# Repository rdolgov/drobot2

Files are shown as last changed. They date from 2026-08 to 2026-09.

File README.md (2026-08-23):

# drobot2

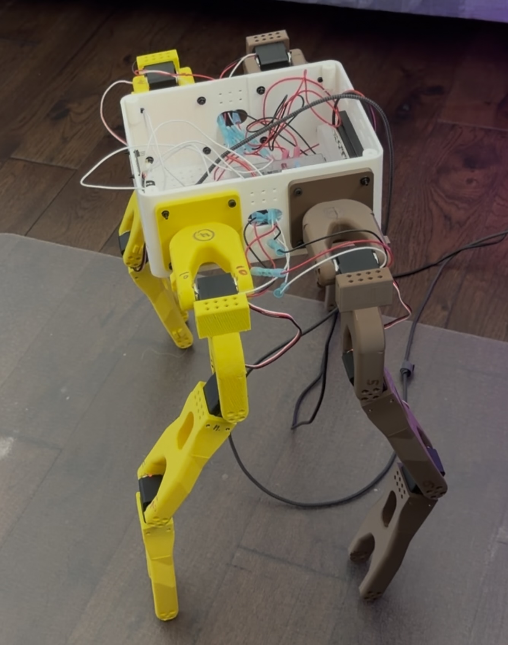
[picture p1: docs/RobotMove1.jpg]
Drobot2 robot in motion


Monorepo for the Drobot2 robot. Engineering areas are separated at the
repository root so CAD, simulation, hardware control, and electrical design
can evolve without sharing one package boundary.

## Physical robot reference

- Measured total assembled robot mass: approximately **3.18 kg** (converted
  from a 7 lb measurement), including the installed rear battery and its
  enclosure as configured on 2026-08-23.

Treat this as the current whole-robot measurement. Component-level CAD and
simulation mass ledgers may differ and should be reconciled against it when
preparing the next dynamics-model or RL-training revision.

## Project areas

- [`cad/`](cad/README.md) — parametric mechanical design,
  CAD-derived URDF generation, manufacturing exports, vendor geometry, and CAD
  review tooling.
- [`simulation/`](simulation/README.md) — Isaac Sim integration, reinforcement
  learning, trained policies, simulator exports, evaluation media, and
  simulation documentation.
- [`hardware/`](hardware/README.md) — one-leg commissioning and four-leg
  hardware control/test applications.
- [`onboard/`](onboard/README.md) — ROS 2 Raspberry Pi runtime, LAN browser
  control, ROS services/topics, and boot-service setup.
- [`electrical/`](electrical/README.md) — power distribution, fusing, wiring,
  schematics, BOM, and power-budget planning.

Run domain-specific commands from the repository root unless that area's
README says otherwise. Shared architecture and repository conventions are
indexed under [`docs/`](docs/README.md). Generated caches and local
environments remain ignored.

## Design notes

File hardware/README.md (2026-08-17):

# Drobot hardware control

This area owns physical robot configuration, commissioning, and guarded local
control software.

## Layout

- [`robot-runtime/`](robot-runtime/README.md) — shared real-robot manifest,
  calibrated servo profiles, neutral centers, and operational helper scripts.
- [`test-apps/`](test-apps/README.md) — one-leg and four-leg commissioning
  applications. These consume `robot-runtime/`; they do not own robot state.

The Raspberry Pi package under [`../onboard/`](../onboard/README.md) reuses
these transport, dashboard, gait, profile, and calibration sources through a
ROS 2 node; it does not maintain a second hardware configuration.

Mechanical design lives in `cad/`, simulation validation in `simulation/`,
and power-system planning in `electrical/`.

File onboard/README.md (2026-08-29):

# Raspberry Pi ROS 2 onboard controller

The selected learned walking policy has a standalone, print-only runtime under
[`policy-runtime/`](policy-runtime/README.md) and a guarded real-motor rollout
inside the port 8080 dashboard. The real rollout uses the BNO085 plus live
12-joint feedback, runs for at most five seconds, and keeps the manual dashboard
as the only servo-bus owner. Stop the port 8090 print-only service before using
the real RL control so only one process reads the BNO085.

See [`docs/pi5-dog-bringup.md`](docs/pi5-dog-bringup.md) for the checked Pi
state, exact setup commands, power notes, and the staged safety plan for moving
from printed targets to real motor control.

This area packages the existing Drobot motor session and browser dashboard as
a ROS 2 node for an onboard Raspberry Pi. The Pi owns the USB servo bus, serves
the control page to computers on the same network, publishes telemetry, and
accepts the same walking commands through ROS services or a ROS command topic.

The package does not copy calibration or gait equations. It imports:

- `hardware/test-apps/one-leg-testbed` for the Feetech transport and calibrated
  angle conversion;
- `hardware/test-apps/four-leg-dashboard` for the twelve-servo session, browser
  UI, continuous distributed crawl, and continuous diagonal-pair gait; and
- `hardware/robot-runtime/four-leg.toml` plus its four tracked servo profiles
  and calibration JSON files as the physical robot source of truth.

## Standalone manual/IK dashboard

The previous inverse-kinematics and manual-walk page can run on the Pi before
ROS 2 is installed. Install it once:

```bash
bash onboard/scripts/install-manual-runtime.sh
bash onboard/scripts/install-manual-web-service.sh --start
```

Open `http://pi5-dog.local:8080/` from a phone or computer on the same trusted
network. The tracked service starts in **DEMO / NO MOTOR OUTPUT** mode. It uses
the real robot profiles, inverse kinematics, crawl logic, and UI with twelve
simulated motors, but it does not open a USB serial device.

After the Feetech USB adapter is connected to the Pi, the power warning is
resolved, and the complete robot is safely supported, edit
`/etc/default/drobot-manual-web`:

```text
DROBOT_MANUAL_DEMO=false
DROBOT_MANUAL_SERIAL_PORT=/dev/ttyUSB0
```

Then restart it with `sudo systemctl restart drobot-manual-web`. Hardware mode
opens the bus, requires all 12 configured IDs, and disarms them before serving
the page. Never run this standalone service and the future ROS motor-owner node
at the same time.

Keep `DROBOT_MANUAL_FALLBACK_DEMO=false` for a robot configured in hardware
mode. Port 8080 remains available as a hardware diagnostics page if the USB
adapter or any configured motor is missing, but every motion control stays
disabled until automatic recovery verifies all 12 IDs and disarms them. Set the
fallback to `true` only when an intentional simulated dashboard is preferred.
The page's mode badge always shows whether output is simulated or connected to
hardware.

### Update an existing Pi dashboard

From the existing clone on the Pi, update the checked-out branch and refresh
the editable runtime installation:

```bash
cd ~/drobot2
git pull --ff-only
bash onboard/scripts/install-manual-runtime.sh
sudo systemctl restart drobot-manual-web
sudo systemctl status drobot-manual-web --no-pager
```

Reload port 8080 after the restart. Confirm the mode badge, `12 / 12` online,
`0 / 12` armed, plausible voltage and temperature, and no fault before using a
whole-robot control. **TEST DISTRIBUTED CRAWL** and **TEST DIAGONAL PAIRS** then
continue until **STOP + STABLE HOLD**. The stop returns to the four-foot gait
stance and keeps torque armed; use **DISARM ALL 12** when support can safely be
removed. A minor off-stance start is accepted and ramped into the computed gait
stance; it is not permission to start from a
folded, collided, unsupported, or visibly damaged pose.

After **SET GAIT START STANCE** reports `COMPLETE / HOLDING`, **TEST DISTRIBUTED
CRAWL** can start directly while all 12 motors continue holding that verified
stance. Partial or unrelated armed configurations remain blocked.

The power panel also shows a basic 3S charge indicator from the last disarmed
idle-voltage reference. It is a pack-level estimate, not a substitute for
checking all three cells through the balance connector.

## Supported Pi baseline

The current `pi5-dog` baseline is a Raspberry Pi 5 with **Ubuntu Server 26.04
64-bit (arm64)** and **ROS 2 Lyrical**. Lyrical supports Ubuntu 26.04 on arm64,
and the image's Python version satisfies the repository's Python
3.11-or-newer requirement.

Official references:

- [ROS 2 Lyrical installation](https://docs.ros.org/en/lyrical/Installation.html)
- [ROS 2 Lyrical Ubuntu arm64 binary support](https://docs.ros.org/en/lyrical/Installation/Alternatives/Ubuntu-Install-Binary.html)
- [Ubuntu Server setup on Raspberry Pi](https://ubuntu.com/tutorials/how-to-install-ubuntu-on-your-raspberry-pi)

Raspberry Pi OS is not the tracked installation target. A source-built or
containerized ROS installation can be added later without changing the package
interfaces.

## Layout

```text
onboard/
|-- ros2_ws/src/drobot_onboard/   ROS 2 ament_python package
|-- scripts/run-manual-web.sh     standalone manual/IK dashboard
|-- scripts/install-pi.sh         dependency install and colcon build
|-- scripts/start-onboard.sh      foreground launcher
`-- systemd/                      optional boot-service template
```

## 1. Prepare the Raspberry Pi

Install ROS 2 Lyrical using the official instructions, including the ROS base
binary archive or equivalent package set. Then install the local build and
serial-account prerequisites:

```bash
sudo apt update
sudo apt install -y git python3-venv ros-dev-tools avahi-daemon
sudo usermod -aG dialout "$USER"
```

Log out and back in after adding `dialout`. This permission is required for
`/dev/ttyUSB*` and `/dev/ttyACM*` devices.

Clone the repository on the Pi:

```bash
git clone YOUR_GITHUB_REPOSITORY_URL ~/drobot2
cd ~/drobot2
```

## 2. Install from the clone

From the repository root:

```bash
bash onboard/scripts/install-pi.sh
```

The script:

1. checks that ROS 2 and Python 3.11+ are available;
2. creates `onboard/.venv` with access to the system ROS Python packages;
3. installs both existing hardware-control packages in editable mode; and
4. builds `drobot_onboard` into `onboard/ros2_ws/install` with symlink install.

The environment, build, install, and log directories stay local and are
ignored by Git.

## 3. Start without hardware first

Demo mode creates twelve in-memory motors and does not open a serial port:

```bash
bash onboard/scripts/start-onboard.sh --demo
```

From another computer on the same network, open:

```text
http://RASPBERRY_PI_HOSTNAME.local:8080/
```

If `.local` name resolution is unavailable, use the Pi's IP address, such as
`http://192.168.1.42:8080/`.

## 4. Start with the robot bus

Connect the Feetech USB adapter and identify its Linux device:

```bash
ls -l /dev/ttyUSB* /dev/ttyACM* 2>/dev/null
```

Then start the controller:

```bash
DROBOT_SERIAL_PORT=/dev/ttyUSB0 bash onboard/scripts/start-onboard.sh
```

`DROBOT_SERIAL_PORT=auto` is the default and works when only one likely USB
serial adapter is connected. Startup opens the bus, verifies servo IDs 1-12,
and leaves every motor disarmed before the web or ROS command interfaces become
available.

The browser exposes the same controls as the desktop dashboard, including:

- telemetry and permanent error display;
- manual per-joint arm, target, leg, and disarm controls;
- calibrated center and gait-start stance;
- continuous distributed crawl;
- continuous diagonal-pair gait; and
- **STOP + STABLE HOLD**, which returns to the four-foot gait stance and keeps
  torque armed; **DISARM ALL 12** remains available separately.

Walking continues until stopped. The browser sends a heartbeat every 0.7
seconds on a request path independent of telemetry. After 20 seconds without
one, the dashboard shows a warning, but the Pi does not stop the gait, change
targets, or remove torque. Page close does not stop or disarm the robot.
ROS-started motion is kept alive by the onboard node until a ROS
stop/disarm request, process shutdown, bus fault, or telemetry/motion fault.
The gait start accepts a minor off-stance measured pose: all motors are armed at
their current positions and ramped toward the computed gait stance. Only the
old zero-centred start-tolerance rejection was removed; all 12 IDs must still
be online, and every computed target must remain inside its calibrated joint
limits.

With `DROBOT_MANUAL_SERIAL_PORT=auto`, the hardware dashboard also recovers
from Linux renumbering the adapter after a USB reconnect. It re-resolves the
current serial device, requires all twelve configured IDs, and disarms every
motor before returning telemetry. A partial bus remains faulted and is never
accepted as a real four-leg controller.

## HTTP web-service API

The browser uses the same JSON API available to other LAN clients. Important
routes are:

| Method and route | Action |
| --- | --- |
| `GET /api/state` | Read telemetry, motor state, gait phase, warnings, and faults |
| `POST /api/crawl-forward` | Start continuous distributed crawl |
| `POST /api/diagonal-pair-forward` | Start continuous diagonal-pair gait |
| `POST /api/crawl-stop` | Stop a hardcoded gait, return to the four-foot stance, and hold torque |
| `POST /api/rl-start` | Start the guarded RL test from the completed all-12 calibrated-center hold |
| `POST /api/rl-stop` | Stop RL inference and disarm all motors |
| `POST /api/power-reset` | Reset rolling power/energy data and capture a fresh idle reference |
| `POST /api/crawl-stance` | Move to the distributed gait stance |
| `POST /api/center-all` | Move all twelve joints to calibrated zero |
| `POST /api/disarm-all` | Disarm all motors |

The standalone Pi service on the trusted LAN does not require a control token.
It requires the non-secret `X-Drobot-Client-Version: 7` compatibility header on
motion-changing POST requests so stale pre-fix pages cannot issue commands.
The current browser supplies it automatically. The future ROS service can still
use its optional configured `DROBOT_CONTROL_TOKEN`.

Example script calls:

```bash
curl http://drobot.local:8080/api/state

curl -X POST -H "Content-Type: application/json" \
  -H "X-Drobot-Client-Version: 7" \
  -d '{"safety_ack":true,"confirmation":"TEST DISTRIBUTED CRAWL"}' \
  http://drobot.local:8080/api/crawl-forward

curl -X POST -H "Content-Type: application/json" \
  -H "X-Drobot-Client-Version: 7" -d '{}' \
  http://drobot.local:8080/api/crawl-stop
```

## ROS 2 interfaces

The launch file places the node in the `/drobot` namespace.

| Interface | Type | Purpose |
| --- | --- | --- |
| `/drobot/status` | `std_msgs/msg/String` | Complete dashboard snapshot encoded as JSON |
| `/drobot/events` | `std_msgs/msg/String` | Last-event changes |
| `/drobot/command` | `std_msgs/msg/String` | Programmatic command input |
| `/drobot/walk_distributed` | `std_srvs/srv/Trigger` | Start continuous one-leg-at-a-time crawl |
| `/drobot/walk_diagonal_pair` | `std_srvs/srv/Trigger` | Start continuous diagonal-pair gait |
| `/drobot/stop` | `std_srvs/srv/Trigger` | Stop gait, return to four-foot stance, and hold torque |
| `/drobot/disarm_all` | `std_srvs/srv/Trigger` | Disarm all motors |
| `/drobot/center_all` | `std_srvs/srv/Trigger` | Move all joints to calibrated zero |
| `/drobot/gait_stance` | `std_srvs/srv/Trigger` | Move to the distributed gait start stance |

Open a second Pi shell and source the environments:

```bash
cd ~/drobot2
source /opt/ros/lyrical/setup.bash
source onboard/.venv/bin/activate
source onboard/ros2_ws/install/setup.bash
```

Examples:

```bash
ros2 topic echo /drobot/status
ros2 service call /drobot/walk_distributed std_srvs/srv/Trigger '{}'
ros2 service call /drobot/walk_diagonal_pair std_srvs/srv/Trigger '{}'
ros2 service call /drobot/stop std_srvs/srv/Trigger '{}'
ros2 topic pub --once /drobot/command std_msgs/msg/String "{data: stop}"
```

Accepted command-topic values are `walk_distributed`, `walk_diagonal_pair`,
`stop`, `disarm_all`, `center_all`, and `gait_stance`. Prefer services when the
caller needs a success/failure response.

## Launch parameters

The launcher reads these environment variables and accepts matching ROS launch
arguments:

| Environment | Launch argument | Default |
| --- | --- | --- |
| `DROBOT_MANIFEST` | `manifest` | `hardware/robot-runtime/four-leg.toml` from the clone |
| `DROBOT_SERIAL_PORT` | `serial_port` | `auto` |
| `DROBOT_HTTP_BIND` | `http_bind` | `0.0.0.0` |
| `DROBOT_HTTP_PORT` | `http_port` | `8080` |
| `DROBOT_CONTROL_TOKEN` | `control_token` | Random token per process |

Direct launch example:

```bash
ros2 launch drobot_onboard onboard.launch.py \
  manifest:="$PWD/hardware/robot-runtime/four-leg.toml" \
  serial_port:=/dev/ttyUSB0 http_port:=8080
```

## Optional start at boot

After the foreground hardware command has worked, install the service:

```bash
bash onboard/scripts/install-systemd-service.sh
```

This enables the service for the current user but does not start it immediately.
Optional overrides, including a stable API token, are placed in
`/etc/default/drobot-onboard`. Start and inspect the service explicitly:

```bash
sudo systemctl start drobot-onboard
systemctl status drobot-onboard
journalctl -u drobot-onboard -f
```

To install and start in one operation, pass `--start`. Node shutdown uses
`SIGINT`, closes the HTTP server, disarms all twelve motors, and closes the
serial bus before systemd restarts or powers down.

## Updating the Pi from Git

```bash
cd ~/drobot2
git pull --ff-only
bash onboard/scripts/install-pi.sh
sudo systemctl restart drobot-onboard
```

Tracked calibration files remain under `hardware/robot-runtime/servos`. Review
calibration changes before pulling over a physical robot installation.

## Network boundary

The dashboard binds to `0.0.0.0` so another device on the LAN can reach it. It
uses the dashboard's per-process request token to reject unrelated API posts,
but it is not an internet-facing authentication system. Keep port 8080 on a
trusted robot network; do not forward it from a router. Set
`DROBOT_HTTP_BIND=127.0.0.1` when only SSH tunneling should reach the UI.

## Troubleshooting

- **Serial permission denied:** confirm the service user belongs to `dialout`,
  then log out/in or reboot.
- **More than one adapter found:** set `DROBOT_SERIAL_PORT` explicitly.
- **IDs missing at startup:** the node intentionally refuses partial startup;
  check robot power, common ground, adapter wiring, and IDs 1-12.
- **Dashboard unreachable:** check `systemctl status`, port 8080, the Pi's IP,
  and the local firewall.
- **Port already occupied:** set `DROBOT_HTTP_PORT` to another unused port or
  stop the older onboard process.
- **Code changed but behavior did not:** rerun `install-pi.sh` and restart the
  foreground process or systemd service.

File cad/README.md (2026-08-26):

# cad

Code-driven CAD area for the Drobot/SO-101 robot inside the Drobot2 monorepo.
Its Python package, specifications, tests, vendor models, and review tooling
remain self-contained under `cad/`.

The current model set was migrated from `simple_drobot` after all local
`text-to-cad` branches were consolidated into its `develop` branch. The
fit-critical ST3215 motor bay and the edited SO-101 upper arm are preserved,
including exact vendor/reference STEP geometry and labeled fit-preview
assemblies.

## Current CAD targets

| Target | Generator | Purpose |
| --- | --- | --- |
| `exports/step/st3215_motor_bay.step` | `drobot_cad/parts/st3215_motor_bay.py` | Printable keyed rear motor bay |
| `exports/step/st3215_servo_visual.step` | `drobot_cad/parts/st3215_servo_visual.py` | Unmodified exact catalog ST3215 geometry for URDF/Isaac visuals |
| `exports/step/upper_arm.step` | `drobot_cad/parts/upper_arm.py` | Complete printable SO-101 upper arm with fused bay and integral output fork |
| `exports/step/st3215_servo_output_fork.step` | `drobot_cad/parts/st3215_servo_output_fork.py` | Reusable ST3215 output fork with a 30 mm negative-X full-edge fusion cap |
| `exports/step/st3215_hip.step` | `drobot_cad/parts/st3215_hip.py` | Printable fused hip in the approved left/down perpendicular pose |
| `exports/step/st3215_hip_body_mount.step` | `drobot_cad/parts/st3215_hip_body_mount.py` | Body-side hip fork with oversized four-bolt mounting plate |
| `exports/step/hip_orientation_preview.step` | `drobot_cad/assembly/hip_orientation_preview.py` | Two-body left/down hip pose checkpoint before printable fusion |
| `exports/step/st3215_motor_bay_fit_preview.step` | `drobot_cad/assembly/st3215_motor_bay_fit_preview.py` | Bay plus exact catalog servo |
| `exports/step/upper_arm_st3215_fit_preview.step` | `drobot_cad/assembly/upper_arm_st3215_fit_preview.py` | Complete upper arm and installed servo |
| `exports/step/robot_arm.step` | `drobot_cad/assembly/robot_arm.py` | Two complete upper arms joined by the elbow ST3215 |
| `exports/step/robot_leg.step` | `drobot_cad/assembly/robot_leg.py` | Body hip mount, perpendicular hip, three exact ST3215 servos, and two linked upper arms |
| `exports/step/rigid_fork_shoe.step` | `drobot_cad/parts/rigid_fork_shoe.py` | Shallow rigid circular shoe with a fork-wrapping saddle and recessed traction pad |
| `exports/step/rigid_fork_shoe_fit_preview.step` | `drobot_cad/assembly/rigid_fork_shoe_fit_preview.py` | Lower-leg, rigid shoe, and two diagonal M3 rod clearance envelopes |
| `exports/step/rectangular_fork_shoe.step` | `drobot_cad/parts/rectangular_fork_shoe.step.py` | 100 x 60 mm flat PLA shoe with a raised fork attachment for increased stability and clearance |
| `exports/step/rectangular_fork_shoe_fit_preview.step` | `drobot_cad/assembly/rectangular_fork_shoe_fit_preview.step.py` | Generated lower-leg preview with four M3 rods and bilateral driver-access envelopes |
| `exports/step/quadruped_body_base.step` | `drobot_cad/parts/quadruped_body.py` | One-piece X2D-safe body tub with hip reinforcement, protected battery rail, four-wall M3 grid, full floor grid, and paired wire ports |
| `exports/step/quadruped_carry_training_handle.step` | `drobot_cad/parts/quadruped_carry_training_handle.step.py` | One-piece side-grid carry handle with two resistance-band attachment slots |
| `exports/step/apriltag_body_marker.step` | `drobot_cad/parts/apriltag_body_marker.step.py` | Two-material tag36h11 ID 0 chassis marker for synchronized video pose tracking |
| `exports/step/apriltag_front_mount_brackets.step` | `drobot_cad/parts/apriltag_front_mount_brackets.step.py` | Pair of M3-grid standoff rails for mounting the AprilTag on the forward-facing body wall |
| `exports/step/quadruped_carry_training_handle_fit_preview.step` | `drobot_cad/assembly/quadruped_carry_training_handle_fit_preview.step.py` | Installed body and handle review assembly |
| `exports/step/quadruped_body_lid.step` | `drobot_cad/parts/quadruped_body_lid.py` | Removable ventilated body lid with a 10 mm-pitch universal M3 grid and direct LeKiwi camera pattern |
| `exports/step/quadruped_electronics_tray.step` | `drobot_cad/parts/quadruped_electronics_tray.py` | Optional electronics tray with four floor-grid-aligned M3 mounting locations |
| `exports/step/cm5202_battery_box.step` | `drobot_cad/parts/cm5202_battery_box.step.py` | Main CM5202 LiPo box with four floor-grid M3 mounts, lid-screw towers, and one upper-left wire port |
| `exports/step/cm5202_battery_box_lid.step` | `drobot_cad/parts/cm5202_battery_box_lid.step.py` | Solid screw-on CM5202 box lid with matching wire relief |
| `exports/step/cm5202_battery_box_fit_preview.step` | `drobot_cad/assembly/cm5202_battery_box_fit_preview.step.py` | Exploded box, measured battery envelope, and lid review assembly |
| `exports/step/cm5202_battery_cradle.step` | `drobot_cad/parts/cm5202_battery_cradle.step.py` | Open CM5202 strap cradle with four floor-grid M3 mounts and wire-side clearance |
| `exports/step/raspberry_pi_5_enclosure_base.step` | `drobot_cad/parts/raspberry_pi_5_enclosure_base.step.py` | Printable Pi 5 box with exact board standoffs and four body-floor grid mounts |
| `exports/step/raspberry_pi_5_enclosure_lid.step` | `drobot_cad/parts/raspberry_pi_5_enclosure_lid.step.py` | Screw-on ventilated lid with exact BNO085 mounting pattern |
| `exports/step/raspberry_pi_5_imu_cover.step` | `drobot_cad/parts/raspberry_pi_5_imu_cover.step.py` | Open-sided removable BNO085 protection roof |
| `exports/step/raspberry_pi_5_enclosure_fit_preview.step` | `drobot_cad/assembly/raspberry_pi_5_enclosure_fit_preview.step.py` | Enclosure, exact Pi 5, lid, exact BNO085, and protection roof review assembly |
| `exports/step/lekiwi_12v_battery_reference.step` | `drobot_cad/parts/lekiwi_12v_battery_reference.py` | Measured 70 x 66 x 40 mm LeKiwi 12 V pack fit proxy |
| `exports/step/waveshare_bus_servo_adapter_a.step` | `drobot_cad/parts/waveshare_bus_servo_adapter_a.py` | Exact Waveshare USB/UART serial-bus controller reference |
| `exports/step/waveshare_bus_servo_adapter_enclosure_base.step` | `drobot_cad/parts/waveshare_bus_servo_adapter_enclosure_base.step.py` | Protective adapter box with body-grid mounts and connector openings |
| `exports/step/waveshare_bus_servo_adapter_enclosure_lid.step` | `drobot_cad/parts/waveshare_bus_servo_adapter_enclosure_lid.step.py` | Screw-on ventilated lid with power-terminal screwdriver access |
| `exports/step/waveshare_bus_servo_adapter_enclosure_fit_preview.step` | `drobot_cad/assembly/waveshare_bus_servo_adapter_enclosure_fit_preview.step.py` | Exploded enclosure preview with exact official Waveshare board geometry |
| `exports/step/adafruit_bno085_stemma_qt.step` | `drobot_cad/parts/adafruit_bno085.py` | Exact Adafruit BNO085 reference centred on its sensing package |
| `exports/step/quadruped_imu_cover.step` | `drobot_cad/parts/quadruped_imu_cover.py` | Printable open-sided BNO085 roof with four aligned M2 nylon through-bolt sleeves |
| `exports/step/quadruped_imu_tray_fit_preview.step` | `drobot_cad/assembly/quadruped_imu_tray_fit_preview.py` | Installed tray, BNO085, and removable protection-cover fit preview |
| `exports/step/quadruped_body_hardware_fit_preview.step` | `drobot_cad/assembly/quadruped_body_hardware_fit_preview.py` | Lighter body, internals, lid, and camera review at full-assembly placements |
| `exports/step/quadruped_robot_fusion360.step` | `drobot_cad/assembly/quadruped_robot.py` | Primary Fusion-ready body, battery, controller, IMU, camera, and four mirrored seven-component ST3215 legs |
| `exports/step/quadruped_robot.step` | `drobot_cad/assembly/quadruped_robot.py` | Byte-identical compatibility copy of the Fusion handoff |
| `exports/step/lekiwi_camera_body_fit_preview.step` | `drobot_cad/assembly/lekiwi_camera_body_fit_preview.py` | Lid positioning preview for the upstream LeKiwi mount and Arducam envelope |

The front lid interface accepts the unchanged LeKiwi
`base_camera_mount.stl`: three M3 clearance holes at 20 mm pitch and a separate
20 x 12 mm cable opening.  The selected compatibility target is LeKiwi's
Arducam 5 MP wide-angle USB option (ASIN `B0972KK7BC`), retained under
`vendor/references/lekiwi/` with upstream license and checksums.

### Rectangular PLA fork shoe

The new rectangular fork-shoe source replaces the hollow TPU rocker with a
fully flat `100 x 60 x 6 mm` PLA contact plate. Its upper sole face is moved to
local `X=24 mm`, leaving `19.05 mm` from the nearest forward M3 hole center to
the plate. A narrow raised spine connects the attachment hub while leaving the
bottom of the fork open; the inherited outer cup was removed after it was found
to collide with the real fork. Even the closest reinforcing rib remains `10.55 mm` outside the
modeled `9 mm` nut-driver envelope. All four existing M3 positions remain
available and are recommended for the longer lever arm.

The owning design record is
[`docs/rectangular-fork-shoe.md`](docs/rectangular-fork-shoe.md), and the focused
generation entry is `scripts/generate_rectangular_fork_shoe.ps1`. The source
and STEP/STL/3MF outputs were regenerated on 2026-08-13. A focused installed
geometry check found zero solid overlap between the new shoe and fork; physical
fit, slicing, and printing remain unverified.

### Universal body-wall mounting grid and wire ports

The one-piece body base now provides M3 clearance holes on all four vertical
walls. The front and rear faces each expose 83 usable locations on a 10 x
10 mm grid after ventilation keep-outs. The left and right walls each expose
12 locations in the protected 36 mm center strip between the hip backing
plates, for 190 body-wall mounting locations in total. These are 3.4 mm
through-holes for bolts, washers, nuts, and standoffs; they are not printed
threads.

Both rounded side wire ports were enlarged from 24 x 14 mm to 32 x 20 mm.
Their centered position is unchanged, and each port retains 2 mm of material
before the neighboring hip reinforcement field. The wall-local hole cutters
do not pass into the battery rail, hip plates, ventilation slots, or lid
interface.

Editable inputs are `drobot_cad/parts/quadruped_body.py` and
`specs/quadruped-body.yaml`. Regenerate every affected committed artifact and
run the focused checks from `cad/` with:

```powershell
.\scripts\generate_cad.ps1 -Force

$cadSkillRoot = Get-ChildItem `
  "$env:USERPROFILE\.codex\plugins\cache\text-to-cad\cad" `
  -Directory | Sort-Object Name -Descending | Select-Object -First 1
$cadSkill = Join-Path $cadSkillRoot.FullName "skills\cad"
$cadpy = Join-Path $cadSkill "scripts\packages\cadpy\src"
$env:PYTHONPATH = ((Resolve-Path ".").Path, $cadpy) -join `
  [IO.Path]::PathSeparator

.\.venv\Scripts\python.exe -m pytest -q `
  tests/test_quadruped_body.py `
  tests/test_quadruped_body_hardware_fit_preview.py `
  tests/test_quadruped_robot_assembly.py `
  tests/test_quadruped_urdf.py `
  tests/test_lekiwi_camera_body_fit_preview.py
.\.venv\Scripts\python.exe -m ruff check `
  drobot_cad/parts/quadruped_body.py `
  tests/test_quadruped_body.py
.\.venv\Scripts\python.exe "$cadSkill\scripts\inspect" refs `
  exports/step/quadruped_body_base.step `
  --facts --planes --positioning --format text
```

The current combined enclosure regression is documented with the body-floor
grid below. Wall-specific inspection still confirms 190 wall-grid cylinders
at 1.7 mm radius, 10.0 mm pitch in each local grid direction, and a 32 x 20 mm
rounded-slot envelope for each side wire port.

### Universal body-floor mounting grid

The four 56 mm-tall molded electronics-tray posts have been removed from the
body. The body floor now provides 255 new M3 clearance holes on a 10 x 10 mm
grid: 119 through the center inside the battery-retaining rail and 136 in the
outer floor bands. Together with four existing M3 and four existing M2 floor
openings, the body has 263 floor mounting locations. A 2 mm minimum web keeps
the raised battery-retaining rail itself solid and uncut.

The optional electronics tray's four M3 holes now align with floor-grid points
at `(+/-80, +/-60) mm`. Its current `Z = 56 mm` assembly placement is only a
clearance reference: no integrated supports, detachable standoff height, or
specific fasteners are selected or modeled. Choose the final tray height with
removable standoffs after the electronics stack and wire bend radii are known.

The new 3.4 mm openings are through-holes, not printed threads. Use bolts,
washers, nuts, or detachable standoffs. Because holes now pass under the
battery envelope, use a nonconductive liner and keep all bolt ends below the
battery. The grid improves mounting flexibility but reduces dust and splash
resistance; floor strength, vibration, fastener retention, and real component
fit still require a physical prototype.

Editable inputs are `drobot_cad/parts/quadruped_body.py`,
`drobot_cad/parts/quadruped_electronics_tray.py`, and
`specs/quadruped-body.yaml`. The focused regression command now covers:

```powershell
.\.venv\Scripts\python.exe -m pytest -q `
  tests/test_quadruped_body.py `
  tests/test_quadruped_body_hardware_fit_preview.py `
  tests/test_quadruped_robot_assembly.py `
  tests/test_quadruped_urdf.py `
  tests/test_lekiwi_body_hardware.py `
  tests/test_quadruped_imu_cover.py `
  tests/test_lekiwi_camera_body_fit_preview.py
.\.venv\Scripts\python.exe -m ruff check `
  drobot_cad/parts/quadruped_body.py `
  drobot_cad/parts/quadruped_electronics_tray.py `
  tests/test_quadruped_body.py
```

Validated on 2026-08-01: all 61 focused tests passed and Ruff passed. STEP
inspection returned one valid body part with 610 faces, 1,795 edges, and the
unchanged 220 x 170 x 96 mm envelope. Baseline comparison confirmed geometry
and topology changed while the envelope did not. The export contains 259 M3
floor cylinders at 1.7 mm radius: 255 grid locations plus four legacy M3
holes. The center hole is open, representative X and Y measurements both
returned 10.0 mm pitch, and the four tray coordinates remain members of the
floor grid. The hardware preview inspected at 2,416 faces and 6,585 edges; the
full robot inspected at 22,128 faces and 60,541 edges with its previous bounds
unchanged. Opposed isometric, top, and installed hardware snapshots were
reviewed successfully. The 107 MB full-robot review mesh closed the snapshot
page during load, so its successful STEP inspection and the lighter
exact-placement hardware preview were used for final enclosure review.

### Universal lid mounting grid

The removable lid now provides 215 usable M3 clearance locations on a 10 x
10 mm pitch across the central 180 x 120 mm mounting field. Of those, 212 are
new holes and the three existing LeKiwi camera holes also land on grid points.
The generator omits local points where a hole would leave less than 2 mm of
material around ventilation slots, cable ports, legacy M2/M3 utility holes, or
the four lid fasteners. The exterior 220 x 170 mm footprint, 4 mm top-plate
thickness, locator lip, camera interface, and body fit are unchanged.

These are 3.4 mm through-holes, not printed threads. Mount a Raspberry Pi,
fuse block, power-distribution board, sensors, or other hardware with M3 bolts,
washers, nuts, and suitable standoffs or with a small adapter plate that picks
up convenient grid points. Hole density and geometric clearance were checked;
payload strength, vibration endurance, component-specific footprints, thermal
behavior, and cable routing still require hardware-level validation.

Editable inputs are `drobot_cad/parts/quadruped_body_lid.py` and
`specs/quadruped-body.yaml`. Regenerate every affected committed artifact and
run the focused checks from `cad/` with:

```powershell
.\scripts\generate_cad.ps1 -Force

.\.venv\Scripts\python.exe -m pytest tests/test_quadruped_body.py -q
.\.venv\Scripts\python.exe -m ruff check `
  drobot_cad/parts/quadruped_body_lid.py `
  tests/test_quadruped_body.py

$cadSkill = "$env:USERPROFILE\.codex\plugins\cache\text-to-cad\cad\0.3.9\skills\cad"
.\.venv\Scripts\python.exe "$cadSkill\scripts\inspect" refs `
  exports/step/quadruped_body_lid.step --facts --planes --positioning --format text
```

Validated on 2026-07-31: the focused body suite passed all 16 tests, a 61-test
body/camera/full-assembly/URDF regression set passed, and Ruff passed. STEP
inspection returned one labeled part shape, 311 faces, 915 edges,
and unchanged 220 x 170 x 7 mm total bounds including the 3 mm underside lip.
The exported topology contains 221 cylindrical M3 faces at 1.7 mm radius (the
215 grid locations plus four lid-fastener and two rear utility holes), and
representative X/Y grid measurements both returned 10.0 mm. Lid, camera-fit,
and installed-body snapshots were reviewed successfully. The full-robot STEP
generated and inspected, but its 80 MB review mesh again closed the snapshot
page during load; the lighter exact-placement body preview remains the visual
review artifact for the enclosure. The full repository test suite was also
attempted but retains unrelated pre-existing failures in the Isaac script-map
documentation and Windows pytest temporary-directory permissions.

Generated outputs are the lid STEP/STL/3MF, the LeKiwi camera fit preview, the
body-hardware fit preview, and the Fusion/compatibility full-robot STEP files
listed above.

The body fit assembly includes the LeKiwi 12 V battery reference and a measured
envelope of the Waveshare Bus Servo Adapter (A). The exact 117-solid controller
is also exported as its own STEP. The battery proxy is 70 x 66 x 40 mm and
sits on the body floor with 1 mm side clearance and 12 mm below the tray's
current reference placement. The body no longer has molded tray supports; the
optional tray requires removable standoffs of a height selected for the final
electronics stack. The adapter sits on four separate M2 board-to-tray
standoffs at the official 37 x 28 mm pattern. LeKiwi calls this a motor control
board; electrically it is a USB/UART
half-duplex serial-bus adapter, not a CAN controller. Pack discharge current,
BMS behavior, connector bend radii, and twelve-servo electrical suitability
remain unvalidated. The proposed fused power, Raspberry Pi, and four-leg data
architecture is documented separately in
[`electrical/README.md`](../electrical/README.md).

The body-centred BNO085 now has a separate printable roof cover. Four
`2.4 mm` holes share the board and tray mounting axes, so four M2 x 20 mm
nylon through bolts and nylon nuts clamp the cover, board, and tray standoffs
as one removable stack. Integrated sleeves seat on the PCB mounting zones,
the roof clears the tallest modeled component by `3.0 mm`, and all four sides
remain open for STEMMA QT wiring and airflow. Use non-magnetic nylon hardware;
an exact M2 x 20 nylon fastener was not available in the checked step.parts
catalog, so fastener geometry is not included in the assembly.

## Review the full assembly in Fusion

Download `exports/step/quadruped_robot_fusion360.step`, then in Fusion use
**File > Open > Open from my computer**, or upload the STEP through the Data
Panel. Fusion translates the STEP into a Fusion design; expand the browser
tree to hide the body lid and inspect the battery, electronics tray,
controller, IMU cover, IMU, and camera references. The STEP contains resolved
static placements and component labels, but not the source-level parametric
history or active servo joints.

## Robot description

| Target | Purpose |
| --- | --- |
| `exports/urdf/quadruped_robot.urdf` | SI-unit description with 15 physical links, one optical frame, 12 actuated joints, camera frames, and the body-centred BNO085 frame |

The URDF generator stays with CAD because its link geometry, inertials, joint
frames, and mesh references are derived directly from the mechanical model.
Isaac import, validation, manual control, walking, stair training, trained
models, and simulator assets live in the sibling
[`simulation/`](../simulation/README.md) package.

STEP is the primary output. STL, 3MF, and intentional GLB files are secondary
manufacturing or interchange exports. Commit these 3D deliverables and regenerate
every affected file whenever its Python generator or YAML specification changes.
Review-only renders, snapshots, Viewer caches, and temporary files stay local and
are ignored by Git.

## Setup

Python 3.11 or newer and Git LFS are required.

```powershell
git lfs install
git lfs pull
py -m venv .venv
.\.venv\Scripts\Activate.ps1
python -m pip install --upgrade pip
python -m pip install -e ".[dev]"
pytest
```

## Preview a Python generator in OCP CAD Viewer

The workspace includes an OCP CAD Viewer task for modules that expose
`gen_step()`.

1. Start **OCP CAD Viewer** from its VS Code sidebar.
2. Open a generator such as `drobot_cad/parts/st3215_motor_bay.py`.
3. Press `Ctrl+Shift+B` and run
   **CAD: Preview current Build123d file in OCP**.

The task builds the in-memory Build123d object and sends it directly to OCP CAD
Viewer. It does not export or overwrite a STEP file. The same preview can be
run from PowerShell:

```powershell
.\.venv\Scripts\python.exe .\scripts\preview_build123d.py `
  .\drobot_cad\parts\st3215_motor_bay.py
```

## Generate the migrated models

The generation helper discovers the installed text-to-cad CAD skill, makes its
assembly runtime available, and regenerates every explicit target above.

```powershell
.\scripts\generate_cad.ps1 -Force
```

## Open 3D preview and markup

```powershell
.\scripts\start_cad_viewer.ps1 `
  -File exports/step/upper_arm_st3215_fit_preview.step
```

Open directly in the six-view markup workspace:

```powershell
.\scripts\start_cad_viewer.ps1 `
  -File exports/step/upper_arm.step `
  -Markup
```

The markup workspace supports front, back, top, bottom, right, and left
orthographic views. Save editable markup as JSON and review sheets as PNG under
`reviews/`. The launcher uses the markup-capable Viewer runtime committed under
`tools/cad-viewer-markup/runtime/`; it does not require another
`text-to-cad` checkout.

See [docs/cad-workflow.md](docs/cad-workflow.md) for the complete generation,
inspection, snapshot, and markup workflow. See
[docs/migration.md](docs/migration.md) for source-history and geometry
provenance. The [documentation index](docs/README.md) identifies the Markdown
owner that must be updated with each CAD or robot-description change.

## Layout

```text
cad/
|-- specs/                 Mechanical design contracts
|-- vendor/                Immutable catalog/reference STEP models
|-- drobot_cad/
|   |-- parts/             Printable part generators
|   |-- assembly/          Labeled, non-printable fit previews
|   `-- urdf/              CAD-derived robot-description generators
|-- scripts/               CAD generation and Viewer launch helpers
|-- tools/                 Project-owned markup patch and Viewer runtime
|-- reviews/               CAD markup and retained design intent
|-- tests/                 CAD, URDF, and provenance checks
`-- exports/               Versioned CAD and URDF deliverables
```

## Vendor-model warning

The migrated source uses the exact Waveshare Feetech **ST3215** catalog model.
No STS3212/ST3212 model was found in step.parts. Do not treat ST3215 as an exact
STS3212 substitute. If the physical robot actually uses STS3212, add its
verified manufacturer STEP and revalidate the cavity before fabrication.

## Monorepo layout

Run the commands in this document from the `cad/` directory. Simulation,
hardware control, and electrical design live in sibling directories at the
Drobot2 repository root; see the
[repository layout and ownership guide](../docs/repository-layout.md).

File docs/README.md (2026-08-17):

# Drobot2 documentation

This directory owns documentation that applies across two or more top-level
project areas. Theme-specific design notes, validation evidence, and operating
instructions stay with the package that owns them.

## Shared documents

- [Repository layout and ownership](repository-layout.md)

## Package documentation

- [CAD and mechanical design](../cad/docs/README.md)
- [Simulation and reinforcement learning](../simulation/docs/README.md)
- [Hardware control](../hardware/README.md)
- [Raspberry Pi ROS 2 onboard control](../onboard/README.md)
- [Electrical design](../electrical/README.md)

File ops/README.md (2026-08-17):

# Raspberry Pi Operations

## Connect to `pi5-dog`

The target device is a Raspberry Pi 5 with 8 GB of RAM. It runs Ubuntu Server
and is connected to the same Orbi LAN as the development computer.

## Role in `drobot2`

This Raspberry Pi is the primary onboard computer for `drobot2`. Its planned
responsibilities include:

- IMU integration and sensor-data handling
- Video capture, processing, and streaming
- CAN bus communication with the robot's embedded devices
- Coordination of the robot's onboard services

Workloads that need more GPU compute may be offloaded over the network to a
remote computer. The Pi remains the onboard integration point for the robot's
hardware and local services while the remote computer handles selected
compute-intensive processing.

Current connection details:

- Hostname: `pi5-dog`
- Hardware: Raspberry Pi 5, 8 GB RAM
- Current IP address: `192.168.1.56`
- SSH username: `rd`
- Wi-Fi SSID: `ORBI32`

From PowerShell on a computer connected to the same network:

```powershell
ssh rd@192.168.1.56
```

Enter the password configured in Raspberry Pi Imager. The SSH password prompt
does not display characters, dots, or asterisks while typing.

If mDNS/Avahi is working on the Pi, the hostname can be used instead:

```powershell
ssh rd@pi5-dog.local
```

The IP address is currently more reliable because hostname discovery has not
always worked on this network.

## Confirm network reachability

```powershell
ping 192.168.1.56
Test-NetConnection 192.168.1.56 -Port 22
```

Port 22 must report `TcpTestSucceeded: True` for SSH to work. Ping may be
blocked even when SSH is available.

If the address changes, open the Orbi app, find `pi5-dog`, and use its current
`192.168.1.x` address. Create an Orbi DHCP reservation for `192.168.1.56` to
keep the address stable.

## Enable hostname discovery

After connecting by IP, install and enable Avahi on the Pi:

```bash
sudo apt update
sudo apt install -y avahi-daemon
sudo systemctl enable --now avahi-daemon
```

The hostname connection should then be available as `pi5-dog.local`.

## Reimage and host-key recovery

Reimaging the card changes the Pi's SSH host key. If SSH reports that the host
identification changed, remove only the old entries and reconnect:

```powershell
ssh-keygen -R 192.168.1.56
ssh-keygen -R pi5-dog.local
ssh rd@192.168.1.56
```

Only remove a stored key when the Pi was intentionally reimaged or its host key
was otherwise knowingly replaced.

## Offline troubleshooting

If Orbi shows the Pi as offline or with address `0.0.0.0`:

1. Allow up to five minutes after first boot for Ubuntu cloud-init setup.
2. Check the Ethernet cable and link/activity lights when using wired access.
3. Confirm the Pi uses a Raspberry Pi 5-compatible 64-bit image and adequate
   USB-C power supply.
4. Inspect the green activity LED for a repeating boot-error pattern.
5. Check the SD card's boot and cloud-init configuration before reimaging.

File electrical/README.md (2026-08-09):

# Quadruped electrical system

This folder is the electrical source of truth for the current twelve-servo
quadruped concept. It covers one 3S battery, four three-servo legs, the
Waveshare Bus Servo Adapter (A), a Raspberry Pi, the USB camera, and the
body-mounted BNO085.

The baseline is intentionally sized for a Raspberry Pi 5. A Pi 4 can use the
same power system with extra margin.

> Status: engineering proposal, not hardware-validated. Wire temperatures,
> voltage drop, fuse behavior, converter temperature, data reliability, and
> walking runtime must be measured on the finished robot before unattended or
> high-load operation.

## Documentation record

- **What changed:** established a complete one-battery architecture for four
  fused servo legs, the Raspberry Pi, and the Waveshare serial-bus adapter.
- **Why:** the earlier four-circuit plan did not include separate fused power
  for compute and controller electronics.
- **Editable sources:** this file, [BOM.md](BOM.md),
  [SCHEMATICS.md](SCHEMATICS.md), and
  [power-budget.csv](power-budget.csv).
- **Reproduction:** from the repository root, run
  `Import-Csv electrical\power-budget.csv | Format-Table -AutoSize` in
  PowerShell to review the retained estimates. There is no generated
  electrical artifact.
- **Validation performed:** manufacturer ratings and connector identities
  were checked against the sources listed below; Markdown/local-link and CSV
  structure were checked. No wire, converter, fuse, battery, data-bus, or
  walking test has been performed.
- **Outputs:** documentation and a CSV planning model only; no CAD geometry,
  PCB, or manufactured harness was generated.
- **Known limitations:** the exact Raspberry Pi model and any additional real
  CAN interface are not selected, component fit on the electronics tray is
  unverified, and every current/runtime figure remains an estimate.

## Important controller naming

The selected Waveshare Bus Servo Adapter (A) is **not CAN bus**. It is a
USB/UART adapter for the ST3215 single-wire, half-duplex TTL serial bus.
Waveshare specifies a 9–12.6 V external input and USB or UART host control.

If a real CAN HAT or CAN controller is added later:

- power it from the Raspberry Pi rail exactly as its manual specifies, never
  directly from the 3S battery unless it explicitly accepts 9–12.6 V;
- keep `CANH` and `CANL` completely separate from the ST3215 `DATA` wire;
- reserve 2 W inside the Raspberry Pi power budget until the exact board is
  selected;
- share system ground unless the selected CAN interface is galvanically
  isolated and its manual says otherwise.

## Baseline architecture

Use one 3S 11.1 V nominal, 12.6 V fully charged battery and one covered
six-circuit ATO/ATC fuse block with an integrated negative bus.

The recommended branch schedule is:

| Circuit | Fuse | Wire | Load |
| --- | ---: | --- | --- |
| 1 | 5 A | 22 AWG to Mini-SPOX pigtail | Front-left leg, 3× ST3215 |
| 2 | 5 A | 22 AWG to Mini-SPOX pigtail | Front-right leg, 3× ST3215 |
| 3 | 5 A | 22 AWG to Mini-SPOX pigtail | Rear-left leg, 3× ST3215 |
| 4 | 5 A | 22 AWG to Mini-SPOX pigtail | Rear-right leg, 3× ST3215 |
| 5 | 5 A | 18 AWG | 3S-to-5 V/5 A Raspberry Pi converter |
| 6 | 1 A | 22 AWG | Waveshare adapter 9–12.6 V input |

Install a separate **30 A main fuse** in 12 AWG wire as close as practical to
the battery-positive connector; target no more than 100 mm (4 in) of
unprotected positive wire. The 30 A fuse protects the main harness. The six
smaller fuses protect the individual branch wires. A fuse does not regulate or
smooth current.

Do not install a fuse in battery negative. Battery negative goes directly to
the fuse block's negative-bus input stud.

See [SCHEMATICS.md](SCHEMATICS.md) for the complete power and data drawings and
[BOM.md](BOM.md) for purchasable parts.

## Why power is split but communication is shared

Each leg still uses the familiar three-wire daisy chain:

`body pigtail → servo 1 → servo 2 → servo 3`

The three conductors are `DATA`, battery positive, and ground. Power enters
each leg through its own 5 A branch fuse, while all four `DATA` conductors meet
the adapter `DATA` conductor in one passive five-port junction.

The adapter's servo-output `VCC` conductor must be disconnected and insulated.
The adapter is powered separately through its green screw terminal on the 1 A
branch. This prevents all twelve servo currents from flowing through the
adapter power path. The official adapter schematic labels that path `MAX:6A`.

The four leg grounds, adapter ground, and Raspberry Pi converter input ground
all terminate on the same negative bus. This common ground provides the
reference for the single-wire data signal.

## Raspberry Pi and controller power

The Raspberry Pi must not receive raw 3S battery voltage.

Use a converter designed for a Pi 5 that accepts the 3S pack range and provides
5 V at 5 A through USB-C. The baseline BOM uses the Pichondria converter:

- input: 6–20 V DC or 2S–4S lithium battery;
- output: 5 V, 5 A;
- use a short, 5 A-rated USB-C cable;
- allow airflow around the converter.

The converter vendor instructs Pi 5 users to set:

```text
usb_max_current_enable=1
```

in `/boot/firmware/config.txt` and `PSU_MAX_CURRENT=5000` in the EEPROM
configuration. Apply those overrides **only** after confirming that the exact
converter, wiring, and USB-C cable are capable of 5 A. A Pi 5 can boot from a
good 5 V/3 A supply, but Raspberry Pi limits downstream USB power when a 5 A
supply is not detected.

The Pi power allowance includes:

- the Raspberry Pi;
- the active cooler/fan;
- the Waveshare adapter's USB logic connection;
- the selected Arducam USB camera;
- the BNO085;
- up to 2 W for a future CAN HAT or other small interface.

The Waveshare adapter also needs its 9–12.6 V screw-terminal input from circuit
6. Set its jumper to the documented USB-control position when connected to the
Pi by USB.

## Servo wiring limits

Waveshare lists the 12 V ST3215 at 200 mA no-load and 2.7 A locked-rotor
current. One leg therefore has:

- 0.6 A total if all three motors are simultaneously spinning with no load;
- 8.1 A theoretical total if all three are locked;
- an expected normal average that must remain well below the locked-rotor
  case.

The Molex Mini-SPOX terminal used by the servo accepts 22–28 AWG wire and the
connector family is rated up to 3 A with 22 AWG under its specified test
conditions. The first connector in a three-servo leg carries the combined leg
current, so it is the limiting connection even though an automotive 5 A fuse
tolerates short motor transients.

Start with the 5 A branch fuses, but verify that each leg remains below 3 A
average and that the first connector does not heat appreciably. If a leg
sustains more than 3 A or the connector rises more than approximately 10 °C
above ambient, add another power-injection point or individual servo power
feeds. Do not simply install a larger fuse.

For the first build, use premade Waveshare 5264-3PIN cables and cut one end to
make the four body pigtails. This is more reliable than learning on the small
Mini-SPOX contacts. The exact parts for later custom crimping are:

- housing: Molex `50375033` / `0050375033`;
- terminal: Molex `08701039` / `0008701039`;
- wire: 22–28 AWG, maximum insulation diameter 1.90 mm.

Never trust wire color or connector orientation alone. Before plugging in a
servo, use continuity mode to verify `DATA`, `VCC`, and `GND` end to end.

## Rough power and runtime estimate

The assumed battery is 3S, 5.2 Ah:

```text
nominal energy = 11.1 V × 5.2 Ah = 57.7 Wh
planning energy = 57.7 Wh × 0.80 = 46.2 Wh
```

The 80% factor reserves energy for voltage sag, converter loss, and avoiding a
deep LiPo discharge. It is not a measured battery test.

| Operating case | Estimated battery power | Estimated runtime |
| --- | ---: | ---: |
| Pi, camera, adapter; servos torque-disabled | 15 W | about 185 min |
| All servos moving unloaded plus electronics | 44 W | about 63 min |
| Light standing/slow motions | 50 W | about 55 min |
| Normal walking planning case | 100 W | about 28 min |
| Aggressive gait/obstacle work | 175 W | about 16 min |
| All twelve servos locked | over 400 W theoretical | fault; do not operate |

A reasonable first expectation is **20–40 minutes of walking from one pack**.
The actual number can be substantially different because gait, robot mass,
foot impacts, servo acceleration, cooling, terrain, and battery sag dominate
the result. The calculations are retained in
[power-budget.csv](power-budget.csv).

At 5.2 Ah and 80C, the pack's advertised discharge figure is
`5.2 × 80 = 416 A`. That is a rating calculation, not a prediction of actual
short-circuit current, but it explains why the 30 A main fuse must remain close
to the battery.

## Battery charging and low-voltage handling

Charge the 3S LiPo only with a balance charger that supports 3S LiPo chemistry.
Connect both the XT60 main lead and the four-wire 3S JST-XH balance lead to the
charger. For a 5.2 Ah pack, a conservative 1C charge rate is 5.2 A; a lower
setting such as 4 A is acceptable and easier on a 50 W charger.

During charging:

- remove the pack from the robot;
- charge on a nonflammable surface in an attended location;
- select `LiPo BALANCE`, 3S, and verify the charger detects three cells;
- never charge a swollen, punctured, hot, or mechanically damaged pack;
- use the charger's storage program before leaving a pack unused for more
  than a few days.

Provide a software warning around 10.5 V under light load and stop testing if
any individual cell approaches the battery manufacturer's minimum. Pack
voltage alone cannot reveal an imbalanced cell, so periodically inspect
per-cell voltage with the balance charger.

## Build sequence

1. Build only the battery connector, 30 A main fuse, and fuse block.
2. With the battery disconnected, verify that positive and negative buses are
   not shorted.
3. Power the empty fuse block and verify battery voltage and polarity.
4. Install the Raspberry Pi converter branch by itself. Verify converter
   polarity and output before connecting the Pi.
5. Install and test the adapter's 1 A branch and USB data connection.
6. Build one leg pigtail and one three-servo chain. Verify every Mini-SPOX pin
   by continuity, then test that leg with the robot mechanically unloaded.
7. Repeat for the other three legs.
8. Add the five-wire passive data junction only after every leg has unique
   servo IDs.
9. Perform the validation below before fitting the lid or walking.

## Required validation

Record the results next to this document before calling the design validated:

- battery polarity and full-charge voltage;
- converter output at Pi idle and CPU/USB load;
- `vcgencmd get_throttled` result during a 10-minute Pi load test;
- idle, standing, normal-walking, and peak battery current;
- current of each leg during the same gait;
- voltage at the first and last servo of every leg;
- first-connector and wire temperature after 10 minutes;
- fuse nuisance trips or discoloration;
- servo packet errors at the selected baud rate;
- battery cell voltages immediately after the walking test;
- measured runtime to the conservative stop threshold.

The five-port `DATA` junction creates a small star topology. It is expected to
work at robot-scale cable lengths but is not yet validated at the ST3215
default 1 Mbps. If packet errors appear, shorten the four stubs, route `DATA`
with a nearby ground, reduce baud rate if supported by the complete software
stack, or change the body wiring to a linear trunk.

## Multiple-battery variants

The baseline uses one pack. Do not parallel packs merely by joining their
positive leads.

For two or four packs, each pack needs its own main fuse and disconnect. Keep
the different battery positives isolated and assign each battery specific leg
branches. All grounds may be joined for the shared TTL data reference. Use
packs of the same chemistry and similar state of charge, and confirm that
removing any one pack cannot back-feed it through the adapter or Raspberry Pi.

Complete and measure the one-battery architecture before changing to multiple
packs; otherwise current-sharing and runtime problems become much harder to
diagnose.

## Sources

Sources and shopping links were checked on 2026-07-29:

- [Waveshare ST3215 product specifications](https://www.waveshare.com/st3215-servo.htm)
- [Waveshare Bus Servo Adapter (A) documentation](https://www.waveshare.com/wiki/Bus_Servo_Adapter_%28A%29)
- [Waveshare Bus Servo Adapter (A) schematic](https://files.waveshare.com/wiki/Bus-Servo-Adapter-%28A%29/Bus%20Servo%20Adapter%20%28A%29-Sch.pdf)
- [Molex Mini-SPOX product specification](https://www.molex.com/content/dam/molex/molex-dot-com/products/automated/en-us/productspecificationpdf/526/5264/52641001-PS-000.pdf)
- [Raspberry Pi power-supply guidance](https://www.raspberrypi.com/documentation/computers/getting-started.html#power-supply)
- [Raspberry Pi 5 USB Power Delivery note](https://pip-assets.raspberrypi.com/categories/685-app-notes-guides-whitepapers/documents/RP-009856-WP-1-USB%20Power%20delivery%20on%20Raspberry%20Pi%205.pdf)
- [Pichondria Pi 5 converter tutorial](https://pichondria.com/usb-pd-2-0-3-0-to-5v-5a-converter-for-raspberrypi-5-tutorial/)

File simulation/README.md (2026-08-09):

# Drobot simulation and learning

This top-level area owns Isaac Sim integration, validation runners,
reinforcement-learning tasks, trained policies, simulator exports, evaluation
media, and their tests and documentation.

## Layout

```text
simulation/
|-- isaac/                 Isaac runners, RL environments, and trained models
|-- exports/isaac/         Versioned USD/USDA/USDC simulator assets
|-- reviews/               Evaluation videos, images, and reports
|-- docs/                  Simulation and learning documentation
|-- tests/                 Isaac-free contract and documentation tests
|-- conversations/         Supplemental simulation engineering records
`-- scripts/               Simulation environment setup helpers
```

CAD-derived URDF inputs remain under `cad/exports/urdf/`. Simulation
outputs consume those inputs and are written under `simulation/exports/isaac/`.
Hardware profiles are read from `hardware/`.

## Setup and tests

Run commands from the repository root:

```powershell
py -m venv cad\.venv
cad\.venv\Scripts\python.exe -m pip install -e ".\cad[dev]"
.\simulation\scripts\setup_isaac_rl.ps1

cad\.venv\Scripts\python.exe -m pytest -q simulation\tests
```

Scripts that import Isaac Sim must use `C:\isaacsim\python.bat`. See the
[Isaac workflow](isaac/README.md) and the [documentation index](docs/README.md)
for exact training, evaluation, and recording commands.

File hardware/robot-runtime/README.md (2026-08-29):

# Shared real-robot runtime

This directory is the source of truth for configuration shared by physical
robot applications. Test applications consume these files but must not keep
their own canonical copies.

## Contents

- [`four-leg.toml`](four-leg.toml) maps the four physical legs to body corners
  and owns dashboard, monitoring, and crawl defaults.
- [`servos/`](servos/) contains each leg's bus settings, servo IDs, directions,
  joint limits, and measured neutral-center calibration.
- [`scripts/`](scripts/) provides guarded status, configuration, calibration,
  and one-leg browser launch helpers using the shared profiles.

## Verified motor map

| Leg | Corner | Servo IDs | Directions | Center ticks |
| ---: | --- | --- | --- | --- |
| 1 | Front left | `1, 2, 3` | `-1, +1, +1` | `2131, 2183, 1005` |
| 2 | Front right | `4, 5, 6` | `+1, +1, +1` | `2022, 2162, 2052` |
| 3 | Rear left | `7, 8, 9` | `-1, -1, -1` | `2020, 2052, 2046` |
| 4 | Rear right | `10, 11, 12` | `+1, +1, +1` | `1998, 2049, 2048` |

The centers were last captured from the assembled whole-robot neutral pose on
2026-08-09. They are specific to this robot and must be revalidated after horn,
servo, wiring, or linkage changes.

All profiles use 1,000,000 baud, a 90% torque limit, speed register 3400,
acceleration register 254, and a 15-degree maximum command step. The dashboard
manual/RL motion ceiling is 270 degrees/s. The hardcoded crawl separately uses
a 120 degrees/s ramp, 6-second cycle, 60 mm stride, and 25 mm lift so only one
leg advances slowly while three feet remain planted. Loaded joints may not
reach no-load speed, and software limits do not replace physical stops or
collision checks. See the
[Waveshare ST3215 documentation](https://www.waveshare.com/wiki/ST3215_Servo)
and the
[ST3215-C047 datasheet](https://files.seeedstudio.com/products/Feetech/108090003_FEETECH_ST-3215-C047-Datasheet.pdf)
for the vendor-level register and electrical context.

## Setup and guarded commands

Install both hardware applications first:

```powershell
.\hardware\test-apps\install-test-apps.ps1
```

Then run helpers from the repository root:

```powershell
.\hardware\robot-runtime\scripts\show-status.ps1 -Leg 4 -Port COM4
.\hardware\robot-runtime\scripts\configure-leg.ps1 -Leg 4 -Port COM4
.\hardware\robot-runtime\scripts\calibrate-leg.ps1 -Leg 4 -Port COM4
.\hardware\robot-runtime\scripts\start-web-control.ps1 -Leg 4 -Port COM4
```

Calibration overwrites the selected shared `calibration-leg-N.json`. The
four-leg dashboard creates timestamped backups under `servos/backups/` before
persisting a multi-leg center capture; that generated backup directory is
ignored by Git.

USB disconnect, browser heartbeat, `Ctrl+C`, and software disarm are not
emergency stops. Support the robot, clear the full linkage sweep, and keep the
physical servo-power cutoff within reach before any command that may arm or
move a motor.

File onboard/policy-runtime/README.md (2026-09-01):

# Raspberry Pi walking-policy runtime

This package runs the selected V30 symmetry-gated, straight-crawl,
external-rear-payload residual policy on a 64-bit
Raspberry Pi with ONNX Runtime. Its standalone CLI and port 8090 UI are
intentionally print-only: they read the
BNO085, assembles the exact 50-value observation, runs deterministic inference
at 60 Hz, converts the 12 normalized actions into bounded/rate-limited joint
targets, and prints the targets with physical servo IDs. It never opens the
servo serial port or enables torque.

Rate limiting uses actual elapsed monotonic time, not the number of loop calls,
and missed deadlines are skipped rather than replayed as catch-up bursts. The
model JSON sidecar declares the supported command range, speed-scaled gait
clock, trained neutral pose, action scales, target slew/packet limits, guarded
startup ramp/settle contract, and the 2,048-sample distributed-crawl reference.
V30 reconstructs the same target used in training as the analytic reference
plus policy residuals scaled by `0.10 / 0.12 / 0.15` for
abduction/hip/knee before rate limiting.

Models may also opt into a metadata-gated relative-heading hold without
changing the 50-value observation shape. At the beginning of each policy run,
the loop captures the BNO085 game-rotation heading as zero. It integrates the
operator's requested yaw rate into a desired relative heading and puts
`requested yaw - bounded proportional heading correction` into the existing
command-yaw observation slot. Sidecars without an enabled `heading_hold`
object retain the legacy requested-yaw behavior exactly. The game rotation
vector deliberately avoids magnetic-north corrections near motors and power
wiring, so it is suitable for short relative-heading holds but can drift over
long runs.

The runtime was exercised on `pi5-dog` with Ubuntu 26.04 ARM64, Python 3.14.4,
ONNX Runtime 1.29.0, and the BNO085 detected at I2C address `0x4A`.

The shared code is split into replaceable interfaces:

- `ImuSource`: BNO085 now, a ROS `sensor_msgs/Imu` adapter later;
- `JointStateSource`: neutral placeholder now, servo telemetry or ROS
  `sensor_msgs/JointState` later;
- `OnnxWalkingPolicy`: portable deterministic policy inference;
- `MotorSink`: JSON printing in the standalone tools, or the guarded callback
  used by the single motor-owning port 8080 dashboard.

`WalkingPolicyLoop` also accepts a passive policy-step observer. The port 8080
dashboard uses it to queue complete real-walk samples for a background JSONL
writer; filesystem work never runs in the policy thread. See
`hardware/test-apps/four-leg-dashboard/docs/rl-recordings.md` for the trial
format and the planned ROS 2/rosbag2 replacement boundary.

## Model

The deployable model is
`onboard/models/parallel-walking-v30-symmetry-gated-robust-straight-crawl/model_5000.onnx`.
It is exported from
`logs/rsl_rl/drobot_commanded_walk_v30_symmetry_gated_robust_straight_crawl_external_rear_payload/2026-08-31_07-15-11_manual-headless/model_5000.pt` with
`simulation/isaac/rl/parallel_walking/export_policy_onnx.py`.

The deployed sidecar accepts the exported `0.005-0.039 m/s` range; its
recommendation remains the conservative `0.005 m/s` first-trial setting.
V30 models the adhesive Velcro-like soles and external rear battery, uses a
25 mm rear-swing load transfer and -12 mm lateral reference correction, and
penalizes reverse motion, path drift, and jerk. A larger valid command changes
cadence up to 0.85 Hz, but low supply voltage can still prevent the servos from
reaching the requested cadence.

The accompanying JSON file records hashes, startup pose, target dynamics, and
the full observation/action ordering. The policy consumes:

1. velocity command (3);
2. gait-clock sine/cosine (2);
3. body-frame gyro, projected gravity, and acceleration (9);
4. joint position error, joint velocity, and previous action (36).

IMU data alone is not sufficient for safe closed-loop motor control. The
standalone tools supply the trained neutral joint pose and zero joint velocity
only to exercise the sensor-to-policy-to-print pipeline. The guarded port 8080
rollout instead provides fresh calibrated 12-joint position/velocity feedback;
see the four-leg dashboard's `specs/rl-walk-v1.md`.

## Install on `pi5-dog`

```bash
ssh rd@pi5-dog.local
cd ~/drobot2
git pull --ff-only
bash onboard/scripts/install-policy-runtime.sh
```

If this is a sparse checkout that currently contains only `hardware/`, add the
onboard directory first:

```bash
git sparse-checkout add onboard
```

The installer creates `onboard/.policy-venv` and installs ONNX Runtime plus the
BNO085 dependencies. Current ONNX Runtime releases provide CPython 3.14 ARM64
wheels; both Pi runtime installers also handle the documented CPython 3.14
`lgpio` wheel used by Blinka.

First verify inference without touching I2C:

```bash
bash onboard/scripts/run-policy-print.sh --imu level --duration-s 5
```

Then read the BNO085 at `0x4A` and print policy motor targets:

```bash
bash onboard/scripts/run-policy-print.sh --imu bno085
```

Stop with `Ctrl+C`. Each output line contains
`"mode":"PRINT_ONLY_NO_SERVO_WRITES"`, the physical servo ID, semantic joint
name, target degrees, and normalized action.

If the sensor board axes do not match robot forward/left/up, pass a signed
permutation. For example, if sensor `+y` is robot forward and sensor `-x` is
robot left:

```bash
bash onboard/scripts/run-policy-print.sh \
  --imu bno085 --imu-axis-map +y,-x,+z
```

Confirm the mounting transform while the robot is supported. When level,
projected gravity should be approximately `[0, 0, -1]`; rotations about each
body axis must have the expected sign before any policy output is connected to
motors. Heading is derived by rotating the configured body-forward axis into
the BNO085 game-world frame, so the same signed permutation applies to both
tilt and relative-yaw feedback.

## Browser dashboard

Start the live, print-only dashboard:

```bash
bash onboard/scripts/run-policy-web.sh --imu bno085
```

Open `http://pi5-dog.local:8090/` from a computer or phone on the same LAN. The
page shows live body-frame IMU values and all 12 policy targets, and can
start/stop inference or adjust the requested forward speed. It also links to
the existing manual crawl dashboard on port 8080. The default Pi service does
not require a token; keep it on a trusted local network.

Token protection remains optional. To enable it deliberately, add a value of
at least 16 characters to `/etc/default/drobot-policy-web` as
`DROBOT_POLICY_TOKEN=...` and restart the service. The page will then show its
unlock form after an unauthorized request.

For automatic startup, install the dedicated service:

```bash
bash onboard/scripts/install-policy-web-service.sh --start
```

The service remains print-only and does not own the servo bus.

The Pi currently reports that its power supply cannot provide 5 A and is
restricting peripheral power. Correct that before depending on an attached USB
servo adapter; the servo rail still requires its own correctly sized supply.

## Recommended ROS 2 boundary

Keep one process as the sole owner of the servo bus. A future policy node should
subscribe to `sensor_msgs/Imu`, `sensor_msgs/JointState`, and a velocity command;
then publish a timestamped 12-joint target message. The existing onboard motor
node should validate freshness, position/rate limits, heartbeat, arming state,
and the physical enable interlock before accepting that message. This preserves
the same policy core while keeping safety enforcement outside the neural
network.

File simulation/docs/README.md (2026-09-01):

# Simulation and learning documentation index

Run documented commands from the repository root. A smoke test proves that a
pipeline executes; it does not prove that a policy converged or transfers to
hardware.

| Topic | Owning document |
| --- | --- |
| Isaac import, sensors, standing, gait, and runtime checks | [`../isaac/README.md`](../isaac/README.md) |
| Flat-ground reinforcement-learning task | [`rl-training.md`](rl-training.md) |
| External rear-battery smooth walking (V20) | [`rl-external-rear-payload-walking-v20.md`](rl-external-rear-payload-walking-v20.md) |
| Low-speed residual crawl (V22) | [`rl-low-speed-residual-crawl-v22.md`](rl-low-speed-residual-crawl-v22.md) |
| Higher-speed straight residual crawl (V23) | [`rl-higher-speed-straight-crawl-v23.md`](rl-higher-speed-straight-crawl-v23.md) |
| Padded-feet forward-bias residual crawl (V24) | [`rl-padded-feet-forward-bias-v24.md`](rl-padded-feet-forward-bias-v24.md) |
| Robust straight low-stance residual crawl design (V25) | [`rl-robust-straight-low-stance-v25.md`](rl-robust-straight-low-stance-v25.md) |
| Forward-biased cycle-gated straight crawl (V28) | [`rl-forward-biased-cycle-gated-v28.md`](rl-forward-biased-cycle-gated-v28.md) |
| Schedule-matched support straight crawl (V29, rejected V30 bootstrap) | [`rl-schedule-matched-support-v29.md`](rl-schedule-matched-support-v29.md) |
| Symmetry-gated robust straight crawl research profile (V30, nominal candidate rejected) | [`rl-symmetry-gated-robust-straight-v30.md`](rl-symmetry-gated-robust-straight-v30.md) |
| Original stair task | [`rl-stairs/README.md`](rl-stairs/README.md) |
| Corrected close-start stair task | [`rl-stairs-v2/README.md`](rl-stairs-v2/README.md) |
| Hardware-informed stair task | [`rl-stairs-v3/README.md`](rl-stairs-v3/README.md) |
| Residual shallow-step task | [`rl-stairs-v5/README.md`](rl-stairs-v5/README.md) |
| Full-size 180 mm stair task | [`rl-stairs-v6-180mm/README.md`](rl-stairs-v6-180mm/README.md) |
| VL53L5CX stair perception | [`rl-stairs-v7-vl53l5cx/README.md`](rl-stairs-v7-vl53l5cx/README.md) |
| Fixed-tread placement | [`rl-stairs-v8-placement/README.md`](rl-stairs-v8-placement/README.md) |
| Pure parallel stair PPO | [`rl-stairs-pure-parallel/README.md`](rl-stairs-pure-parallel/README.md) |
| Foot-lift PPO | [`rl-foot-lift-v1/README.md`](rl-foot-lift-v1/README.md) |
| Scripted stair feasibility | [`stair-feasibility/README.md`](stair-feasibility/README.md) |
| Later stair transfer audits | [`rl-stairs-v12-lift-hold/README.md`](rl-stairs-v12-lift-hold/README.md), [`rl-stairs-v13-direct-lift/README.md`](rl-stairs-v13-direct-lift/README.md), [`rl-stairs-v19-v21-transfer-audit/README.md`](rl-stairs-v19-v21-transfer-audit/README.md), and [`rl-stairs-v22-live-transfer/README.md`](rl-stairs-v22-live-transfer/README.md) |

Mechanical sources remain under [`../../cad/`](../../cad/README.md),
hardware commissioning under [`../../hardware/`](../../hardware/README.md), and
electrical design under [`../../electrical/`](../../electrical/README.md).

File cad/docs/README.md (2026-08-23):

# CAD documentation index

`cad/` owns mechanical design and CAD-derived robot descriptions only.
Simulation, learning, hardware-control, and electrical documentation live in
their corresponding top-level areas.

| Topic | Owning document |
| --- | --- |
| CAD generation and visual review | [`cad-workflow.md`](cad-workflow.md) |
| Imported design history | [`migration.md`](migration.md) |
| Coordinate conventions | [`../specs/coordinate-system.md`](../specs/coordinate-system.md) |
| Mechanical interfaces and part contracts | [`../specs/`](../specs/) |
| CM5202 screw-lid battery box | [`cm5202-battery-box.md`](cm5202-battery-box.md) |
| CM5202 open strap cradle | [`cm5202-battery-cradle.md`](cm5202-battery-cradle.md) |
| Raspberry Pi 5 enclosure and IMU roof | [`raspberry-pi-5-enclosure.md`](raspberry-pi-5-enclosure.md) |
| Waveshare Bus Servo Adapter enclosure | [`waveshare-bus-servo-adapter-enclosure.md`](waveshare-bus-servo-adapter-enclosure.md) |
| Carry and resistance-band training handle | [`quadruped-carry-training-handle.md`](quadruped-carry-training-handle.md) |
| Rectangular PLA distal-fork shoe | [`rectangular-fork-shoe.md`](rectangular-fork-shoe.md) |
| Rigid low-profile distal-fork shoe | [`rigid-fork-shoe.md`](rigid-fork-shoe.md) |
| Superseded TPU distal-fork shoe | [`tpu-fork-shoe.md`](tpu-fork-shoe.md) |
| CAD-derived URDF assumptions | [`../specs/quadruped-urdf-ledger.md`](../specs/quadruped-urdf-ledger.md) |
| Purchasable/reference geometry provenance | [`../vendor/README.md`](../vendor/README.md) |

Related areas:

- [Simulation and reinforcement learning](../../simulation/README.md)
- [Hardware control and commissioning](../../hardware/README.md)
- [Electrical design](../../electrical/README.md)

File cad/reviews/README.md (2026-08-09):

# CAD review artifacts

Store editable CAD Viewer orthographic markup JSON and exported PNG review
sheets here. Prefer names that include the target and intent, for example:

`upper_arm-cable-route-three-view-markup.json`

The `legacy/` folder retains design intent brought from the source project.
Generated verification snapshots belong under `exports/renders/` instead.

Simulator evaluation media belongs in [`../../simulation/reviews/`](../../simulation/reviews/).

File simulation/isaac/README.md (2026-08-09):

# Isaac Sim 6.0 quadruped checks

This is the owning guide for the robot's Isaac import, articulation, sensors,
gravity checks, scripted gait, and reinforcement-learning handoff. Start with
the committed world for learning and inspection; rebuild the USD assets only
after the URDF changes.

## How the files connect

The simulation has one direction of data flow:

```text
cad/drobot_cad/urdf/quadruped_robot.py
                 |
                 v
cad/exports/urdf/quadruped_robot.urdf
                 |
                 v
simulation/isaac/import_quadruped.py
          |                         |
          v                         v
fixed robot USDC             floating robot USDC
          |                         |
          |                         v
          |          simulation/isaac/create_manual_world.py
          |                         |
          |                         v
          |       simulation/exports/isaac/quadruped_robot_manual_world.usda
          |                         |
          v                         v
 camera validation       manual control, IMU, standing,
                         crawl, PPO training, PPO evaluation
```

The URDF defines the links, inertias, collision shapes, joint axes and limits,
and actuator limits. The importer turns that description into a USD
articulation and adds the Isaac camera, IMU, and self-collision filters. The
manual-world builder references the floating articulation and adds the floor,
gravity, contact material, starting height, rated servo cap, and standing
targets. Runtime scripts then open that same world; they do not construct a
different robot.

Use the two imported variants for different questions:

| Variant | Base behavior | Use it for |
| --- | --- | --- |
| fixed | base is attached to the world | joint structure and camera validation |
| floating | base responds to gravity and contact | standing, gait, IMU, manual control, and RL |
| one-leg wall testbed | the physical 76 mm hip plate is fixed flush to a vertical wall | isolated three-joint range, wall clearance, gravity load, and direct joint control |

All robot coordinates are SI units with `+X` forward, `+Y` left, and `+Z` up.
Joint positions are radians in Python even though USD angular-drive target
attributes are authored in degrees.

## How a Python command launches Isaac

Use `C:\isaacsim\python.bat`, not the project's ordinary Python, for every
script that imports `isaacsim`. `python.bat` selects Isaac's bundled Python and
its Omniverse extension paths. Each entry-point then:

1. parses its command-line options;
2. constructs `SimulationApp`, which starts Kit/Isaac in headless or GUI mode;
3. imports Omniverse APIs after the app exists;
4. opens or creates a USD stage;
5. runs physics and reads the articulation or sensors;
6. writes a JSON report and returns a non-zero process exit code on failure;
7. closes `SimulationApp`.

You do not need to launch Isaac separately before using these commands. A GUI
script such as `open_articulation.py` starts Isaac and opens the requested
world for you. Double-clicking the USDA in Isaac is also possible, but the
launcher is more reproducible because it verifies the robot path, 12 joints,
13 imported rigid bodies, camera, IMU, and rated effort cap first.

Pure NumPy contract tests do use ordinary project Python because they do not
start the simulator:

```powershell
python -m pytest `
  tests\test_quadruped_isaac_runtime.py `
  tests\test_quadruped_imu_observation.py `
  tests\test_quadruped_rl_contract.py
```

## One-leg wall testbed

The isolated wall setup answers the same question as the physical home test
without the quadruped body, other legs, ground, or stair contacts. Its fixture
frame uses `+X` forward along the wall, `+Y` away from the wall, and `+Z` up.
The exact printable body-side mount is shown with its 76 x 76 mm plate back
face flush to the vertical wall. The moving hip and two arm links reuse the
quadruped URDF geometry, collision proxies, joint frames, masses, and
inertias. There is deliberately no virtual foot sphere.

The tracked model records the locally calibrated 2026-07-28 physical setup:

| Motor | Logical testbed range | Encoder direction | Positive model motion |
| --- | ---: | ---: | --- |
| 1 hip abduction | `-45 to +45 deg` | `+1` | leg moves away from the wall |
| 2 hip flexion | `-90 to +90 deg` | `-1` | hanging leg moves toward wall-frame `+X` |
| 3 knee | `-120 to +120 deg` | `-1` | distal link bends toward wall-frame `+X` at zero flexion |

All three captured center ticks are `2048`. These are physically exercised
isolated-testbed ranges, not automatically approved whole-robot limits. Body
interference, four-leg cable routing, support contact, loaded current, and
continuous thermal behavior still require separate checks.

Generate, import, and sweep the explicit artifacts from the repository root:

```powershell
$projectPython = '.\cad\.venv\Scripts\python.exe'
$urdfTool = 'C:\Users\roman\.codex\plugins\cache\text-to-cad\cad\0.3.9\skills\urdf\scripts\urdf'
$isaacPython = 'C:\isaacsim\python.bat'

& $projectPython $urdfTool `
  cad\drobot_cad\urdf\one_leg_wall_testbed.py `
  -o cad\exports\urdf\one_leg_wall_testbed.urdf

& $isaacPython simulation\isaac\import_one_leg_wall.py `
  --urdf cad\exports\urdf\one_leg_wall_testbed.urdf `
  --output simulation\exports\isaac\one_leg_wall_testbed.usdc `
  --report simulation\isaac\output\one-leg-wall\import_report.json

& $isaacPython simulation\isaac\run_one_leg_wall.py `
  --gravity both `
  --screenshot simulation\reviews\isaac-one-leg-wall-range.png
```

The automatic runner verifies the local `leg.toml` ranges/directions and
`calibration.json` centers when those ignored machine-local files exist. It
then checks each joint at two degrees inside both hard endpoints and checks
two combined poses, first with zero gravity and then with Earth gravity.
The default `0.8825985 N*m` effort cap is 30% of published stall torque to
mirror the hardware register value of 300 only nominally; the ST3215 register
is not a calibrated linear joint-torque sensor.

For direct viewport control of the same articulation:

```powershell
& $isaacPython simulation\isaac\run_one_leg_wall.py --interactive
```

Use `1`, `2`, or `3` to select the joint, hold `Up`/`Down` to move its target,
press `Z` to zero it, `G` to toggle gravity, `R` to reset all targets, `C` to
print state, and `X` or `Esc` to save the session report and exit. Wall
contact, hard joint limits, velocity limits, moving-link self-collision, drive
gains, and the selected effort cap remain active.

The 2026-07-28 Isaac 6.0.1 run imported one articulation root, four rigid
bodies, three revolute drives, and two filtered moving-pivot pairs. With wall
contact active, the isolated leg produced:

| Test | Zero gravity | Earth gravity |
| --- | ---: | ---: |
| hip abduction toward wall, target `-43 deg` | stopped at `-10.250 deg` | stopped at `-10.250 deg` |
| hip abduction away from wall, target `+43 deg` | `42.999 deg` | `41.377 deg` after 2 s |
| hip flexion, targets `+/-88 deg` | max error `0.0019 deg` | max error `1.4932 deg` after 2 s |
| knee, targets `+/-118 deg` | max error `0.0038 deg` | max error `0.3519 deg` after 2 s |
| combined `(30, 60, -90) deg` | max error `0.0020 deg` | max error `1.0537 deg` after 2 s |

The reverse combined pose also stopped only on inward hip abduction. Repeating
the zero-gravity sweep with `--disable-wall-contact` made all eight endpoint
and combined poses pass; the worst error was `0.00382 deg`. This diagnostic
proves the negative-abduction stop is the flush wall envelope, not a frozen
Isaac drive. Keep wall contact enabled for the physical fixture; use the
option only to compare a clamp, stand, or wall-edge setup that gives the leg
clearance behind the plate.

Two follow-up probes on the unchanged full quadruped fixed asset also passed:
front-left hip flexion reached `40 deg` with `0.00093 deg` error and the knee
reached `70 deg` with `0.00196 deg` error, both reaching 90% motion in about
`0.383 s` under zero gravity. The prior full-scene failure therefore did not
show that Isaac was unable to move the arm. The stair gate remains a loaded
floating-base support/contact problem: its IK targets were already inside the
old limits, while the previous run saturated rated effort, lost three-foot
support, slipped, and tipped before achieving the requested foot lift.

Local reports are:

- `simulation/isaac/output/one-leg-wall/import_report.json`
- `simulation/isaac/output/one-leg-wall/range_report.json`
- `simulation/isaac/output/one-leg-wall/range_report_no_wall_contact.json`
- `simulation/isaac/output/motor-physics-audit/wall-followup-hip-flexion.json`
- `simulation/isaac/output/motor-physics-audit/wall-followup-knee.json`

The reviewed render is `simulation/reviews/isaac-one-leg-wall-range.png`.

## First interactive run

From the repository root in a fresh clone:

```powershell
git lfs pull
$isaacPython = 'C:\isaacsim\python.bat'
if (-not (Test-Path -LiteralPath $isaacPython)) {
  throw "Isaac Sim Python was not found at $isaacPython"
}

& $isaacPython simulation\isaac\open_articulation.py `
  --world simulation\exports\isaac\quadruped_robot_manual_world.usda `
  --report simulation\isaac\output\manual-open.json
```

The committed `quadruped_robot_manual_world.usda` references
`quadruped_robot_floating.usdc` in the same `simulation/exports/isaac` directory. Git LFS
must therefore download both files, and they must stay together.

Once the window opens:

1. wait for the robot and floor to appear;
2. press **Play** if the timeline is paused;
3. open **Physics > Articulation Inspector**;
4. select `/World/Robot`;
5. move one joint by a small amount and observe the corresponding leg;
6. stop the timeline before closing the application.

The launcher applies the conservative standing target once, then stops sending
commands. The Inspector therefore owns subsequent target changes. Add
`--onboard-camera` to begin in the mounted camera view. Run with
`--headless --smoke-seconds 2` when only the automated
open/physics/sensor check is needed.

## Script map

Every maintained simulation source file is indexed here. Files beginning with
an underscore are imported helpers and are not launched directly.

| Source | What it does | Reads | Writes or changes |
| --- | --- | --- | --- |
| `simulation/scripts/setup_isaac_rl.ps1` | Installs and verifies the pinned PPO dependencies in Isaac's Python | `simulation/isaac/rl/requirements.txt` | Isaac Python environment |
| `simulation/isaac/import_quadruped.py` | Imports fixed or floating URDF, authors camera/IMU/self-collision metadata, validates structure, optionally flattens to one USDC | generated URDF and its meshes | imported USD plus import JSON |
| `simulation/isaac/import_one_leg_wall.py` | Imports the physically configured fixed wall-mounted one-leg URDF and preserves wall contact while filtering two intentional moving-pivot overlaps | generated one-leg URDF and its meshes | monolithic one-leg USDC plus import JSON |
| `simulation/isaac/run_one_leg_wall.py` | Runs zero/Earth-gravity endpoint and combined-pose sweeps or opens direct 1/2/3 joint viewport control | one-leg USDC and optional local hardware config/calibration | range or interactive JSON and optional PNG |
| `simulation/isaac/create_manual_world.py` | Builds the portable gravity/contact world around the floating asset | floating USDC | manual-world USDA plus JSON |
| `simulation/isaac/open_articulation.py` | Starts the GUI or a headless smoke run and leaves manual GUI control unopposed | manual-world USDA | optional open-run JSON |
| `simulation/isaac/validate_quadruped.py` | Checks fixed structure or floating standing stability, joint tracking, effort, tilt, and height | fixed or floating USD | validation JSON and optional PNG |
| `simulation/isaac/run_crawl.py` | Commands the scripted crawl or contact-verified quasi-static sequence | floating USD | gait metrics JSON and review PNG |
| `simulation/isaac/validate_camera.py` | Renders known colored targets through the mounted RTX camera and validates RGB/depth buffers and orientation | fixed USDC | camera JSON and onboard PNG |
| `simulation/isaac/validate_imu.py` | Holds the stand, samples the body IMU, and validates gravity, quaternion, rates, and the nine-value IMU block | manual-world USDA | IMU JSON |
| `simulation/isaac/_quadruped_runtime.py` | Owns joint names, servo torque/speed constants, leg inverse kinematics, stance, crawl, and target ordering | no simulator asset | Python values used by validation, gait, and RL |
| `simulation/isaac/_imu_observation.py` | Converts Isaac IMU frames into hardware-oriented body axes and a finite nine-value observation | IMU frame dictionaries | NumPy observation arrays |
| `simulation/isaac/rl/quadruped_walk_v1.yaml` | Versions the task, action scale, reward, reset, termination, and PPO settings | edited by the trainer and evaluator | no generated data |
| `simulation/isaac/rl/requirements.txt` | Pins Gymnasium, Stable-Baselines3, TensorBoard, and YAML packages | setup script | no generated data |
| `simulation/isaac/rl/_rl_contract.py` | Pure NumPy definition of the 48-value observation, reward terms, and termination decisions | state arrays and YAML values | observations and scalar reward breakdown |
| `simulation/isaac/rl/_quadruped_rl_env.py` | Implements Gymnasium `reset()`/`step()` against the real Isaac articulation and IMU, with a pre-physics-play hook for task-specific contact tensor registration | manual world and task config | actions, observations, rewards, episode state |
| `simulation/isaac/rl/train_ppo.py` | Creates `SimulationApp`, wraps the environment, trains/resumes PPO, checkpoints, and records provenance | YAML, manual world, optional checkpoint | model ZIP, TensorBoard, monitor CSV, training JSON |
| `simulation/isaac/rl/play_ppo.py` | Reloads a saved policy and runs deterministic evaluation episodes | YAML, manual world, model ZIP | evaluation JSON and optional PNG |
| `simulation/isaac/rl/record_ppo.py` | Records one deterministic flat-policy episode through an external or onboard RTX camera | YAML, manual world, model ZIP | H.264 MP4, thumbnail PNG, recording JSON |
| `simulation/isaac/rl/foot_lift/__init__.py` | Marks the supported single-foot-lift task as a separate Python source package | no runtime input | no generated data |
| `simulation/isaac/rl/foot_lift/quadruped_foot_lift_v1.yaml` | Versions the supported 190 mm lift gate, 200 mm IK reference, measured hardware cap, residual action, reward, termination, and PPO settings | edited by foot-lift runners | no generated data |
| `simulation/isaac/rl/foot_lift/quadruped_foot_lift_v2_balance.yaml` | Versions the unsupported 190 mm gate, five-stage clearance curriculum, 300 mm stance, 45 mm diagonal weight transfer, support-triangle reward, and measured hardware cap | edited by foot-lift runners | no generated data |
| `simulation/isaac/rl/foot_lift/quadruped_foot_lift_v3_rear_right_balance.yaml` | Mirrors the unsupported balance task onto the rear-right leg needed next in the stair sequence, retaining the strict 190 mm hold gate and measured hardware cap | edited by foot-lift runners | no generated data |
| `simulation/isaac/rl/foot_lift/_foot_lift_contract.py` | Defines the 56-value observation, smooth lift reference, reward, explicit failure reasons, and strict 190 mm hold gate | walking observation, measured skill state, and YAML values | observations and scalar contract results |
| `simulation/isaac/rl/foot_lift/_quadruped_foot_lift_env.py` | Applies the raise-forward IK reference, optional torso pose hold, lift curriculum, bounded PPO residuals, support-triangle measurement, foot-tip measurements, and episode metrics | manual world and foot-lift config | actions, observations, rewards, and supported/unsupported lift metrics |
| `simulation/isaac/rl/foot_lift/train_foot_lift_ppo.py` | Runs smoke/full/final-stage PPO training, optional flat or same-shape skill transfer, lift curriculum, checkpointing, and schema-2 model packaging | foot-lift YAML/world and optional initializer | model ZIP, manifest, monitor/TensorBoard data, and training report |
| `simulation/isaac/rl/foot_lift/train_foot_lift_v3_rear_right_190mm_small.ps1` | Runs the bounded fresh 512-step rear-right 190 mm final-stage training job | V3 foot-lift YAML and manual world | V3 model, manifest, checkpoints, and training report |
| `simulation/isaac/rl/foot_lift/evaluate_foot_lift_ppo.py` | Verifies the model manifest and runs deterministic supported-lift episodes | foot-lift YAML/world, model, and manifest | evaluation JSON and optional PNG |
| `simulation/isaac/rl/foot_lift/record_foot_lift_ppo.py` | Records one deterministic supported lift with a best-lift thumbnail | foot-lift YAML/world, model, and manifest | H.264 MP4, thumbnail PNG, and recording JSON |
| `simulation/isaac/rl/stairs/__init__.py` | Marks the stair experiment as a separate Python source package | no runtime input | no generated data |
| `simulation/isaac/rl/stairs/quadruped_stairs_v1.yaml` | Versions the stair geometry, terrain inputs, curriculum, reward, reset, termination, action, and PPO settings | edited by stair runners | no generated data |
| `simulation/isaac/rl/stairs/quadruped_stairs_v2.yaml` | Corrects the stair task with a close reset, navigation observations, physical-height reward, mastery curriculum, bounded exploration, and progress watchdog | edited by stair runners | no generated data |
| `simulation/isaac/rl/stairs/quadruped_stairs_v3.yaml` | Applies the exercised one-leg joint ranges and nominal 30%-of-stall torque cap while widening the stair action box | edited by stair runners | no generated data |
| `simulation/isaac/rl/stairs/quadruped_stairs_v4.yaml` | Corrects flat-policy action scaling and matches its effective 120 Hz action cadence | edited by stair runners | no generated data |
| `simulation/isaac/rl/stairs/quadruped_stairs_v5.yaml` | Defines the frozen-flat residual controller, staged 10-40 mm worlds, physical fork-tip shaping, strict elevation/hold success, and measured hardware limits | edited by stair runners | no generated data |
| `simulation/isaac/rl/stairs/quadruped_stairs_v6_180mm.yaml` | Defines the fixed-250 mm-depth height curriculum through the exact 180 mm stage, 68-value foot-sequence input, strict four-foot landing gate, and measured hardware limits | edited by stair runners | no generated data |
| `simulation/isaac/rl/stairs/quadruped_stairs_v7_vl53l5cx.yaml` | Reuses the exact 180 x 250 mm world and measured hardware limits while replacing analytic terrain input with a 15 Hz noisy/latent 8 x 8 VL53L5CX raycast contract | edited by stair runners | no generated data |
| `simulation/isaac/rl/stairs/quadruped_stairs_v8_single_tread_placement.yaml` | Defines the blind five-phase front-left placement curriculum, exact 180 x 250 mm geometry, force-backed tread/support gate, slip threshold, and measured hardware cap | edited by stair runners | no generated data |
| `simulation/isaac/rl/stairs/quadruped_stairs_v9_front_pair_placement.yaml` | Composes front-left/front-right skills around an incenter-targeted, force/margin/velocity-gated mixed-height body transfer; current conservative run passes transfer and reaches 163 mm right lift | edited by stair runners | no generated data |
| `simulation/isaac/rl/stairs/quadruped_stairs_v10_front_right_single_tread_placement.yaml` | Mirrors the blind force-backed 180 x 250 mm single-tread curriculum for the independently verified front-right leg | edited by stair runners | no generated data |
| `simulation/isaac/rl/stairs/quadruped_stairs_v13_front_right_stabilized_lift.yaml` | Isolates a strict supported front-right 190 mm lift beside the exact 180 x 250 mm tread, with no custom friction | edited by stair runners | no generated data |
| `simulation/isaac/rl/stairs/quadruped_stairs_v14_front_pair_right_then_left.yaml` | Composes verified right-foot placement with a snapshot-stabilized left-foot lift/placement mastery curriculum; current bounded run reaches the 100 mm gate and isolates post-transfer body-clearance loss | edited by stair runners | no generated data |
| `simulation/isaac/rl/stairs/quadruped_stairs_v15_front_left_stabilized_lift.yaml` | Mirrors the strict supported-lift curriculum for the front-left leg and gates 190 mm clearance, three-foot support, slip, and upright hold beside the exact 250 mm tread | edited by stair runners | no generated data |
| `simulation/isaac/rl/stairs/quadruped_stairs_v16_front_pair_proprioceptive_support.yaml` | Replays the verified right-foot placement, performs a force/margin-gated body transfer, then trains a support-only PPO residual through progressive left-foot lift and contact stages; RGB remains disabled | edited by stair runners | no generated data |
| `simulation/isaac/rl/stairs/quadruped_stairs_v22_front_pair_torque_aware.yaml` | Slows the transferred left-foot lift to 3 s and extends the placed front-right support target by 50 mm under the real-test torque cap; exact tread depth remains 250 mm | edited by stair runners | no generated data |
| `simulation/isaac/rl/stairs/quadruped_stairs_v23_front_pair_support_regulation.yaml` | Adds stance load, composite-COM error, and requested-effort saturation observations for live front-pair support training | edited by stair runners | no generated data |
| `simulation/isaac/rl/stairs/quadruped_stairs_v24_front_pair_conservative_support.yaml` | Pins a strict randomized 190 mm front-left transfer drill with reward ordering that makes late drift/falls worse than early physical success | edited by stair runners | no generated data |
| `simulation/isaac/rl/stairs/quadruped_stairs_v25_front_pair_load_sharing.yaml` | Tests direct stance-height load redistribution during the transferred 190 mm lift; retained as a rejected ablation | edited by stair runners | no generated data |
| `simulation/isaac/rl/stairs/quadruped_stairs_v26_front_pair_smoothed_load_sharing.yaml` | Low-pass filters and bounds the rejected load-sharing ablation for a same-seed causal comparison | edited by stair runners | no generated data |
| `simulation/isaac/rl/stairs/quadruped_stairs_v36_transfer_support_residual.yaml` | Isolates a two-second post-transfer support catch before the rear-right swing on the exact 180 x 250 mm stair, with a compact nine-action residual and measured hardware effort cap | edited by stair runners | no generated data |
| `simulation/isaac/rl/stairs/quadruped_stairs_v37_joint_clearance_support.yaml` | Stages the post-transfer rear-pitch correction and joins the frozen V17/V35 rear-right swing with V36 support control on the exact 180 x 250 mm stair | edited by stair runners | no generated data |
| `simulation/isaac/rl/stairs/quadruped_stairs_v42_com_margin_rear_right_landing.yaml` | Clips the rear-right landing balance target into the live support polygon at a positive margin while preserving the measured effort cap and exact 180 x 250 mm stair | edited by stair runners | no generated data |
| `simulation/isaac/rl/stairs/quadruped_stairs_v43_compliant_rear_right_touchdown.yaml` | Adds bounded rear-right tread-load feedback for compliant touchdown diagnosis | edited by stair runners | no generated data |
| `simulation/isaac/rl/stairs/quadruped_stairs_v44_early_contact_rear_right_landing.yaml` | Accepts force-backed post-clearance tread contact, latches the landing reference during the strict hold, and applies searched asymmetric support reach plus pitch regulation | edited by stair runners | no generated data |
| `simulation/isaac/rl/stairs/quadruped_stairs_v45_rear_left_transfer.yaml` | Extends the accepted three-foot prefix only far enough to expose the rear-right-to-rear-left transfer for the next COM search | edited by stair runners | no generated data |
| `simulation/isaac/rl/stairs/quadruped_stairs_v46_rear_right_sidestep.yaml` | Repositions the landed rear-right foot outward/deeper on the same 250 mm tread before exposing the rear-left COM transfer | edited by stair runners | no generated data |
| `simulation/isaac/rl/stairs/_stair_geometry.py` | Defines the crack-free stacked collision layers for the four-step staircase | stair YAML values | pure Python geometry facts |
| `simulation/isaac/rl/stairs/_vl53l5cx_contract.py` | Defines pure 8 x 8 ray geometry, 15 Hz mode validation, bounded noise/dropout, three-lane compression, and 24 depth observation fields | sensor YAML values and NumPy grids | rays and normalized depth observations |
| `simulation/isaac/rl/stairs/_vl53l5cx_sensor.py` | Samples 64 PhysX closest-hit rays, rotates the body sensor into world space, and applies update cadence, hold, and latency | live base pose and sensor config | raw/noisy grids, hit paths, and 24-value depth observation |
| `simulation/isaac/rl/stairs/_stair_rl_contract.py` | Defines selectable analytic or hardware-shaped terrain input, observation contracts through the 95-value support-regulation form, placement phases/contact gates, measured-state transfer re-anchoring, three- and four-foot load correction math, progress gates, strict stair/foot goals, physical-height reward terms, and failure reasons | walking/terrain/placement observation and stair YAML values | observations and scalar contract results |
| `simulation/isaac/rl/stairs/_quadruped_stairs_env.py` | Extends walking with exact DOF order, dynamic swing/support residual scales, pre-play force tracking, five-phase placement, mass-weighted whole-robot COM regulation, staged pitch correction, opt-in four-foot transfer preload, instrumented stance load-sharing ablations, per-leg slip and reachable-reference metrics, optional foot-friction sensitivity, selectable analytic/VL53L5CX perception, curriculum, and episode gates | stair world and task config | actions, observations, rewards, contact/sensor and episode state |
| `simulation/isaac/rl/stairs/_placement_phase_training.py` | Replays verified precursor phases and composes a frozen full-action base plus a second compact masked residual before exposing a bounded trainable target residual | stair environment and verified PPO policies | phase-local observations, actions, resets, and training metrics |
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

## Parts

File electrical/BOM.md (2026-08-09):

# Electrical bill of materials

This BOM implements the one-battery architecture in [README.md](README.md) and
is the procurement source of truth for the current electrical, compute,
actuator, walking-policy sensor, and stair-depth hardware. Printed structures,
custom brackets, and their final fastener lengths remain controlled by the CAD
and mechanical specifications rather than this electrical BOM.

Core power links were checked on 2026-07-29. Compute, actuator, sensor, and
policy-runtime links were checked on 2026-08-07. Price, stock, seller, and
included accessories can change.

## Core power system

| Qty | Part | Recommended item / buy link | Notes |
| ---: | --- | --- | --- |
| 1 | 3S battery | [Zeee 3S 11.1 V 5200 mAh 80C XT60](https://zeeebattery.com/products/zeee-3s-lipo-battery-5200mah-11-1v-80c-xt60-1) | Existing or equivalent pack; confirm physical size before purchase |
| 1 | Balance charger | [HOTA D6 Pro overview](https://hotachargers.com/) or [Amazon ASIN B0827S7NYV](https://www.amazon.com/dp/B0827S7NYV) | Buy an authentic unit; AC-powered, dual-channel, 1S–6S LiPo balance and storage charging; useful if two packs are owned |
| 1 | Six-circuit fuse block with negative bus | [Blue Sea Systems 5025](https://www.bluesea.com/products/5025/ST_Blade_Fuse_Block_-_6_Circuits_with_Negative_Bus_and_Cover) or [Amazon ASIN B000THQ0CQ](https://www.amazon.com/dp/B000THQ0CQ) | Six positive fuse positions and six negative returns; 100 A block rating, 30 A per circuit |
| 1 | Main inline fuse holder | [Littelfuse FHAS100-BP](https://www.littelfuse.com/products/fuse-blocks-fuseholders-and-fuse-accessories/automotive-and-commercial-vehicle-fuse-holders/ato-mini-sealed-fuse-holders/fhas100-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) | Sealed ATO holder, 12 AWG leads, 30 A maximum |
| 2 | 30 A ATO/ATC fuses | [Littelfuse ATO fuses at Mouser](https://www.mouser.com/c/circuit-protection/fuses/automotive-fuses/?series=ATO) | One installed at battery positive, one spare |
| 6 | 5 A ATO/ATC fuses | [Littelfuse ATO fuses at Mouser](https://www.mouser.com/c/circuit-protection/fuses/automotive-fuses/?series=ATO) | Four legs, Pi converter, and one spare |
| 2 | 1 A ATO/ATC fuses | [Littelfuse ATO fuses at Mouser](https://www.mouser.com/c/circuit-protection/fuses/automotive-fuses/?series=ATO) | Adapter branch and one spare |
| 1 pair | Battery connector | [Genuine Amass XT60H pair](https://www.stevensaero.com/product/xt60-connector-pair/) | Match battery polarity; accepts 12 AWG |
| 1 m each | 12 AWG red and black stranded copper wire | Local automotive, marine, or RC supplier | Battery, main fuse, and fuse-block studs; keep short |
| 2 m each | 18 AWG red and black stranded copper wire | Local automotive or marine supplier | Pi converter input |
| As needed | Heat-shrink ring/fork terminals | Match 12, 18, and 22 AWG plus Blue Sea #10-32 studs/#8-32 screws | Use a real ratcheting crimper and perform a pull test |

The Blue Sea 5025 is the clean recommendation because its fifth and sixth
circuits account for the Raspberry Pi and servo adapter. A cheaper six-way
fuse block can work, but its real terminal material, current rating, and screw
retention should be inspected rather than trusted from the listing alone. The
5025's published weight is approximately 0.25 kg, so its tray fit and mass
penalty must be reviewed before purchase; it is electrically convenient, not
yet mechanically approved for this robot.

## Raspberry Pi and controller

| Qty | Part | Recommended item / buy link | Notes |
| ---: | --- | --- | --- |
| 1 | Onboard computer | [Raspberry Pi 5, 4 GB](https://www.raspberrypi.com/products/raspberry-pi-5/) | Selected baseline for 60 Hz policy inference; 4 GB is sufficient for the current walking actor, while 8 GB is optional for heavier ROS 2 or vision workloads |
| 1 | Boot storage | [Raspberry Pi A2 microSD card, 32 GB or 64 GB](https://www.raspberrypi.com/products/sd-cards/) | Install 64-bit Raspberry Pi OS; retain a reproducible image after the hardware runtime is validated |
| 1 | Raspberry Pi 5-capable battery converter | [Pichondria 6–20 V / 2S–4S to 5 V 5 A converter](https://www.tindie.com/products/regaldreamtech/usb-pd-2030-to-5v-5a-converter-board-for-rpi5/) | Connect its DC solder pads to circuit 5; follow its Pi configuration tutorial |
| 1 | Short USB-C to USB-C power cable | 5 A, e-marked, 100 W or higher cable from a reputable vendor | Short/thick cable minimizes the 5 V drop |
| 1 | Waveshare Bus Servo Adapter (A) | [Waveshare product/documentation](https://www.waveshare.com/wiki/Bus_Servo_Adapter_%28A%29) | Existing selected controller; USB/UART TTL, not CAN |
| 1 | Short USB-A to USB-C data cable | [Adafruit 6 in USB A-to-C data cable](https://www.adafruit.com/product/4472) | Pi host to adapter; must carry data, not only power |
| 1 | Raspberry Pi 5 active cooler | [Official Raspberry Pi 5 Active Cooler](https://www.raspberrypi.com/products/active-cooler/) | Required for sustained enclosed operation; include its fan in the Pi power budget |

If an existing robot already uses a Pi 4, the same converter and the current
small policy should be usable after a measured 60 Hz timing test. New builds
should use the Pi 5 above. Raspberry Pi recommends 5 V/3 A for Pi 4 and 5 V/5 A
for full Pi 5 peripheral power.

## Policy sensors and camera

| Qty | Role | Exact item / buy link | Requirement and wiring notes |
| ---: | --- | --- | --- |
| 1 | Body IMU | [Adafruit BNO085 9-DOF Orientation IMU Fusion Breakout, product 4754](https://www.adafruit.com/product/4754) | **Required for flat walking and stairs.** This exact board matches the CAD envelope and mount; use the game rotation vector so servo-current magnetic fields do not enter the state estimate |
| 1 | Raspberry Pi I2C-to-QT adapter | [Adafruit Pi STEMMA QT Breakout, product 6365](https://www.adafruit.com/product/6365) | Solderless prototype connection from the Pi GPIO I2C pins to the BNO085; confirm final tray and cooler clearance before retaining it in the robot |
| 1 | Pi-to-IMU I2C cable | [Adafruit 100 mm STEMMA QT/Qwiic cable, product 4210](https://www.adafruit.com/product/4210) | Connect the Pi STEMMA QT breakout to either BNO085 QT port; route away from servo power conductors |
| 1 | Stair depth sensor | [Pololu VL53L5CX 8x8-zone ToF carrier, item 3417](https://www.pololu.com/product/3417) | **Required for the trained stair/depth observation, not for flat walking.** Use full 8x8 mode at 15 Hz; do not substitute a single-zone VL53 sensor |
| 1 | IMU-to-depth I2C cable | [Adafruit QT-to-female-sockets cable, select the 150 mm female-socket option](https://www.adafruit.com/product/4209) | Daisy-chain from the BNO085's second QT port to the Pololu carrier's `VIN`, `GND`, `SDA`, and `SCL` header pins; verify labels and continuity rather than relying only on wire color |
| 1 | RGB review/teleoperation camera | [Arducam 5 MP wide-angle USB camera, ASIN B0972KK7BC](https://www.amazon.com/dp/B0972KK7BC) | Selected camera envelope; optional for recording and teleoperation, and **not** an input to the current flat-walking or VL53L5CX stair actors |

The BNO085 and VL53L5CX use different I2C addresses, but the shared real bus
still needs a bench test for initialization, update rate, dropped reads,
electrical noise, and recovery behavior before powered walking. Remove any
shipping/protective film from the VL53L5CX optical package before testing.

## Actuators

| Qty | Part | Exact item / buy link | Notes |
| ---: | --- | --- | --- |
| 12 | Joint servo | [Waveshare/Feetech ST3215 serial-bus servo](https://www.waveshare.com/st3215-servo.htm) | Select the **30 kg.cm at 12 V ST3215** option. Do not substitute ST3215-7.4V, ST3215-HS, ST3235, or STS3212; assign and record 12 unique bus IDs before assembly |
| 1 optional | Spare joint servo | [Same 12 V ST3215](https://www.waveshare.com/st3215-servo.htm) | Recommended commissioning spare from the same purchase batch |

The model and power plan use the regular 12 V ST3215 feedback, velocity, and
torque characteristics. The servo driver board is separate and is listed in
the Raspberry Pi/controller section above.

## Servo power and data harness

| Qty | Part | Recommended item / buy link | Notes |
| ---: | --- | --- | --- |
| 2 packs | 300 mm 5264-3PIN servo cables, six per pack | [Waveshare premade cables](https://www.waveshare.com/sr-cable-5264-3pin.htm) | Eight leg jumpers, one adapter data pigtail, three spares |
| 1 pack | 900 mm 5264-3PIN servo cables, six per pack | [Waveshare premade cables](https://www.waveshare.com/sr-cable-5264-3pin.htm) | Cut to make four body-to-leg pigtails; two spares |
| 1 | Five-port data junction | [WAGO 221-415](https://www.wago.com/us/wire-splicing-connectors/compact-splicing-connector/p/221-415) or [Amazon ASIN B06XH47DC2](https://www.amazon.com/dp/B06XH47DC2) | Adapter `DATA` plus four leg `DATA` wires; all five ports are common |
| As needed | 22 AWG flexible stranded wire, red/black/white | Electronics or RC supplier | Mini-SPOX maximum supported wire size is 22 AWG |
| As needed | Braided sleeve and strain relief | Electronics supplier | Protect all four moving leg harnesses from pinching and abrasion |
| 1 | Multimeter with continuity mode | Existing tool | Mandatory for connector polarity checks |

For later fully custom cables:

| Qty | Part | Buy link | Notes |
| ---: | --- | --- | --- |
| 10 | Molex Mini-SPOX 3-position housing `50375033` | [DigiKey Mini-SPOX family](https://www.digikey.com/en/product-highlight/m/molex/mini-spox-wire-to-board-connector-system) | Buy spares |
| 50 | Molex terminal `08701039` | [DigiKey Mini-SPOX family](https://www.digikey.com/en/product-highlight/m/molex/mini-spox-wire-to-board-connector-system) | 22–28 AWG, 1.90 mm maximum insulation diameter |
| 1 | Correct open-barrel crimp tool | [Official Molex `638281900`](https://www.molex.com/en-us/products/part-detail/638281900) | The official tool is expensive; premade cables are preferred for the first robot |

Do not substitute a connector because it merely looks like JST-XH. The servo
connector is 2.50 mm Molex Mini-SPOX/5264.

## Optional safety and measurement items

| Qty | Item | Purpose |
| ---: | --- | --- |
| 1 | LiPo charging container or quality charging bag | Reduces exposure to nearby combustible material; it does not make charging unattended-safe |
| 1 | 3S cell checker/low-voltage alarm | Quick per-cell check through the balance connector |
| 1 | DC clamp meter or inline RC watt meter rated above 30 A | Measure real gait current and refine the runtime model |
| 1 | Easily reachable DC-rated disconnect | Provides a fast shutdown method; the battery XT60 remains the final physical disconnect |
| 1 | Spare set of 1 A, 5 A, and 30 A fuses | Replace only after finding the cause of a blown fuse |

For any powered walking test, the reachable DC-rated disconnect, multimeter,
and appropriate spare fuses above are commissioning requirements, not optional
conveniences. Begin with the chassis restrained or suspended and keep a person
at the physical disconnect.

## Policy runtime artifacts and software

These are not purchased parts, but they complete the Pi handoff and prevent a
hardware order from being mistaken for a deployable controller:

- Copy both
  [`policy.onnx`](../simulation/isaac/models/parallel-walking-v16/exported/policy.onnx)
  and
  [`policy.onnx.data`](../simulation/isaac/models/parallel-walking-v16/exported/policy.onnx.data)
  to the same directory on the Pi. The second file contains the external model
  weights and is required by the first.
- Use 64-bit Raspberry Pi OS and the CPU
  [`onnxruntime`](https://onnxruntime.ai/docs/get-started/with-python.html)
  package for deterministic inference.
- The flat-walking loop must run at `60 Hz` and reproduce the exact 48-value
  observation order: command `3`, BNO085 angular velocity `3`, projected
  gravity `3`, acceleration divided by `9.81` `3`, joint-position error `12`,
  joint velocity divided by `4.5836625 rad/s` `12`, and previous action `12`.
- The selected V16 model is documented in
  [`parallel-walking-v16/README.md`](../simulation/isaac/models/parallel-walking-v16/README.md).
  It remains a simulation checkpoint rather than a hardware-deployment release;
  a watchdog, sensor/servo fault handling, action rate limiting, restrained
  bring-up, and measured loop timing are still required.
- For later stair sensing, use ST's
  [VL53L5CX Linux driver](https://www.st.com/en/embedded-software/stsw-img025.html)
  and preserve the trained 8x8-at-15-Hz compression/latency contract.

## If the existing four-way ELECTOP block was already purchased

The [ELECTOP four-way positive fuse block](https://www.amazon.com/dp/B0CN92862F)
can still feed the four legs. The
[Blue Sea 2314 covered MiniBus](https://www.amazon.com/dp/B000OTJ89Q) can still
serve as the common negative bus.

However, those two parts do not provide fused positive outputs for the Pi and
adapter. Add:

- one covered positive bus, such as the
  [Blue Sea 2304/2314 100 A MiniBus](https://www.bluesea.com/products/2304/Common_100A_Mini_BusBar_-_5_Gang);
- one 5 A inline ATO holder from that positive bus to the Pi converter;
- one 1 A inline ATO holder from that positive bus to the adapter;
- a cover for every exposed positive bus.

The main-feed sequence becomes:

`battery + → 30 A main fuse → disconnect → covered positive bus`

The positive bus then feeds the ELECTOP input, the 5 A Pi inline fuse, and the
1 A adapter inline fuse. This is electrically workable but larger and usually
costs more than replacing the distribution parts with one six-circuit 5025.

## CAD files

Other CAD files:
cad/.tmp-lekiwi-parts/controller/Bus Servo Adapter (A).step
cad/.tmp-lekiwi-parts/lekiwi_12v_5ah_battery_reference.stl
cad/drobot_cad/parts/exports/3mf/rectangular_fork_shoe.3mf
cad/exports/step/st3215_hip.step
cad/exports/stl/apriltag_body_marker_white.stl
cad/templates/apriltag_body_marker_bambu_source.3mf
cad/exports/step/apriltag_front_mount_brackets.step
cad/exports/stl/apriltag_body_marker_black.stl
cad/exports/step/apriltag_body_marker.step
cad/exports/step/waveshare_bus_servo_adapter_enclosure_fit_preview.step
cad/exports/step/waveshare_bus_servo_adapter_enclosure_base.step
cad/exports/step/waveshare_bus_servo_adapter_enclosure_lid.step
cad/exports/step/quadruped_carry_training_handle.step
cad/exports/step/quadruped_carry_training_handle_fit_preview.step
cad/exports/step/raspberry_pi_5_enclosure_lid.step
cad/exports/step/raspberry_pi_5_enclosure_fit_preview.step
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

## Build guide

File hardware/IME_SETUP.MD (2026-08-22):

# BNO085 IMU Setup on Raspberry Pi 5

This guide records the working BNO085 setup on `pi5-dog` so it can be repeated after an OS or environment rebuild.

## Tested configuration

- Raspberry Pi 5, 64-bit (`aarch64`)
- Ubuntu Raspberry Pi kernel
- Python 3.14 virtual environment: `~/bno085-env`
- Adafruit Blinka 9.2.0
- Adafruit CircuitPython BNO08x 1.3.3
- `lgpio` 0.2.2.0
- BNO085 I2C address: `0x4A`

## Wiring

| BNO085 | Raspberry Pi 5 |
| --- | --- |
| VIN | 3.3 V |
| GND | GND |
| SDA | GPIO 2, physical pin 3 |
| SCL | GPIO 3, physical pin 5 |

## Enable I2C and install system tools

```bash
sudo raspi-config nonint do_i2c 0
sudo apt update
sudo apt install -y i2c-tools python3-venv
```

## Create the virtual environment

```bash
python3 -m venv ~/bno085-env
source ~/bno085-env/bin/activate
python -m pip install --upgrade pip
python -m pip install adafruit-blinka adafruit-circuitpython-bno08x
```

Activate it again in future shells with:

```bash
source ~/bno085-env/bin/activate
```

## Python 3.14 `lgpio` installation

On 64-bit Raspberry Pi OS/Ubuntu, PyPI may try and fail to build `adafruit-lgpio` under Python 3.14. Install Adafruit's prebuilt CPython 3.14 ARM64 wheel instead:

```bash
python -m pip install https://github.com/adafruit/lgpio-python-wheels/raw/main/wheels/lgpio-0.2.2.0-cp314-cp314-linux_aarch64.whl
```

Do not use this exact wheel on a non-`aarch64` system or with a Python version other than 3.14. Check first with:

```bash
uname -m
python --version
```

## Device permissions

Blinka needs access to both `/dev/gpiochip0` and `/dev/i2c-1`. Add the login user to the device groups:

```bash
sudo /usr/sbin/usermod -aG dialout,i2c "$USER"
```

Log out completely and reconnect so the new group membership takes effect. A reboot is not required. Verify after reconnecting:

```bash
id
```

The output must include both `dialout` and `i2c`.

## Verify the hardware

Check that the sensor appears at `0x4A`:

```bash
i2cdetect -y 1
```

Test Blinka and scan the bus using short commands that are safe to paste into a terminal:

```bash
python -c "import board; print('GPIO access OK')"
python -c "import board,busio; i=busio.I2C(board.SCL,board.SDA); print(i.scan())"
```

The scan should print `[74]`; decimal 74 is hexadecimal `0x4A`.

## Read the BNO085

Save the following as `bno085_test.py` or run it from a Python editor:

```python
import time

import board
import busio
from adafruit_bno08x import (
    BNO_REPORT_ACCELEROMETER,
    BNO_REPORT_GAME_ROTATION_VECTOR,
    BNO_REPORT_GYROSCOPE,
)
from adafruit_bno08x.i2c import BNO08X_I2C

i2c = busio.I2C(board.SCL, board.SDA)
imu = BNO08X_I2C(i2c, address=0x4A)

imu.enable_feature(BNO_REPORT_ACCELEROMETER)
imu.enable_feature(BNO_REPORT_GYROSCOPE)
imu.enable_feature(BNO_REPORT_GAME_ROTATION_VECTOR)

time.sleep(1)
print("BNO085 connected. Press Ctrl+C to stop.")

while True:
    print(
        "accel:", imu.acceleration,
        " gyro:", imu.gyro,
        " quaternion:", imu.game_quaternion,
    )
    time.sleep(0.2)
```

Run it with:

```bash
source ~/bno085-env/bin/activate
python bno085_test.py
```

## Feed the walking policy

After the standalone sensor check succeeds, install and run the repository's
print-only policy pipeline:

```bash
cd ~/drobot2
bash onboard/scripts/install-policy-runtime.sh
bash onboard/scripts/run-policy-print.sh --imu bno085
```

For a phone/computer view instead of terminal JSON:

```bash
bash onboard/scripts/run-policy-web.sh --imu bno085
```

Open the tokenized `http://pi5-dog.local:8090/` URL printed by the command.

This reads the same acceleration, gyro, and game quaternion reports and prints
the resulting 12 motor targets without opening the servo bus. See
`onboard/policy-runtime/README.md` for the observation contract, mounting-axis
mapping, and the required joint-feedback work before motor actuation.

## Troubleshooting

### `ModuleNotFoundError: No module named 'lgpio'`

Install the matching `lgpio` wheel described above.

### `lgpio.error: 'can not open gpiochip'`

Check `id`. The current login session must include `dialout`. Also check:

```bash
ls -l /dev/gpiochip0
```

### Permission error opening `/dev/i2c-1`

Check `id`. The current login session must include `i2c`. Also check:

```bash
ls -l /dev/i2c-1
```

### Sensor not found

Run `i2cdetect -y 1`, recheck power and wiring, and confirm whether the board uses address `0x4A` or `0x4B`. Update the `address=` argument if necessary.

### I2C frequency warning

Blinka may warn that I2C frequency is not settable from Python. This is benign on Linux; the working code leaves out the `frequency=400000` argument.

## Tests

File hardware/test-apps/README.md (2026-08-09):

# Hardware test applications

The hardware test applications are peer packages:

- [`one-leg-testbed/`](one-leg-testbed/README.md) — guarded ST3215 setup,
  telemetry, bounded movement, and single-leg browser control.
- [`four-leg-dashboard/`](four-leg-dashboard/README.md) — twelve-servo
  commissioning dashboard and deterministic crawl controls.

The current wide mirrored 45-degree commissioning gait, hip-abduction stance,
Isaac boundary, and supported hardware test ladder are documented in the
[`crawl walk V4 spec`](four-leg-dashboard/specs/crawl-walk-v4.md). V2 and V3
remain alongside it as historical design evidence.

Both applications read shared physical-robot state from
[`../robot-runtime/`](../robot-runtime/README.md).

Install both into the one-leg testbed's shared virtual environment from the
repository root:

```powershell
.\hardware\test-apps\install-test-apps.ps1
```

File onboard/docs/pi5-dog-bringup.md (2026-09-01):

# `pi5-dog` bring-up record

Last checked: 2026-08-31

This records the current Raspberry Pi state and the safe rollout path from
print-only policy inference to closed-loop walking. Do not place login
passwords, dashboard tokens, or Wi-Fi credentials in this repository.

## Current Pi baseline

| Item | Observed state |
| --- | --- |
| Host | `pi5-dog.local` |
| Board / OS | Raspberry Pi 5, Ubuntu 26.04 LTS arm64 |
| Python | 3.14.4 |
| IMU | BNO085 detected at `0x4A` |
| IMU bus | Software I2C `/dev/i2c-8` on GPIO 2/3 for BNO085 clock stretching |
| Policy model | `parallel-walking-v30-symmetry-gated-robust-straight-crawl/model_5000.onnx` |
| Model SHA-256 | `c93e9e58349326a56fa5846c72fd0c4ba8da3babf12dc2ce2bebdaf2fe01d564` |
| Policy runtime | ONNX Runtime 1.29.0, 60 Hz, deterministic Beta mean |
| Motor output | Standalone 8090 tools are print-only; port 8080 provides guarded real control |
| Manual/IK dashboard | Boot service on port 8080; hardware preference with safe demo fallback |
| USB servo adapter | QinHeng USB serial, stable by-id path when connected; currently removable |
| ROS 2 | Not installed during this check; Lyrical is the tracked Ubuntu 26.04 target |

The Pi reported that its supply could not provide 5 A and was restricting
peripheral power. Fix the Pi supply before depending on a USB servo adapter.
The servo rail must continue to use its own correctly sized supply with a
shared signal ground. A kernel update was also pending; reboot only during a
planned maintenance window.

## One-time policy setup

For a normal clone:

```bash
ssh rd@pi5-dog.local
cd ~/drobot2
git pull --ff-only
git lfs install
git lfs pull
bash onboard/scripts/install-policy-runtime.sh
```

For an existing sparse clone that does not include `onboard/`:

```bash
cd ~/drobot2
git sparse-checkout add onboard
git lfs install
git lfs pull
bash onboard/scripts/install-policy-runtime.sh
```

The installer verifies that the ONNX file is not a Git LFS pointer and checks
its SHA-256 against the tracked model metadata.

### Required BNO085 I2C setting

The BNO085 uses clock stretching and can be unreliable on Raspberry Pi hardware
I2C. A typical symptom is `('Was not able to enable feature', 1)` when RL Walk
tries to enable the accelerometer report. The sensor can still appear normally
at `0x4A` and return its product ID while every streaming report fails.

The Pi 5 hardware controller accepts only standard bus rates and registered at
about 97.5 kHz even when `i2c_arm_baudrate=10000` was requested. The tracked
configuration therefore uses Linux's clock-stretching-compatible software I2C
controller on the same GPIO 2/3 wires. No sensor rewiring is required.

Configure software bus 8 at approximately 100 kHz once, then reboot:

```bash
bash onboard/scripts/configure-bno085-i2c.sh
sudo reboot
```

The script preserves the previous boot configuration as
`/boot/firmware/config.txt.drobot-bno085-backup`, disables hardware I2C on GPIO
2/3, adds the `i2c-gpio` overlay, and sets `DROBOT_BNO085_I2C_BUS=8` for the
manual dashboard service. After reboot, verify the bus without starting the
servo controller:

```bash
ls -l /dev/i2c-8
sudo i2cdetect -y 8
```

Do not reduce the software bus to 10 kHz for the RL runtime. That rate allowed
the three BNO085 reports to activate, but it could not deliver a combined
accelerometer, gyro, and orientation sample fast enough for control. The
software controller is used for correct clock stretching, not to sacrifice the
sensor bandwidth needed by the policy.

Observed recovery on 2026-08-29 required removing power from the BNO085 before
software bus 8 could enable all three reports. After that hard power-cycle, the
approximately 100 kHz software bus initialized the IMU in 2.4 seconds and
returned valid gyro, gravity, and acceleration values. In a 120-sample
scheduled 60 Hz check, combined reads measured 9.1 ms median, 19.6 ms p95, and
45.6 ms maximum; 7 reads exceeded one 16.7 ms frame, but none approached the
controller's 120 ms hard deadline. Treat future report-enable failures as a
reason to stop, disarm, and hard-power-cycle the sensor rather than repeatedly
pressing RL Start.

Do not try to solve this error only with repeated RL Start attempts. If it
continues on software bus 8, power-cycle the IMU/Pi and check the 3.3 V, ground, SDA,
and SCL connections. The Pi's persistent 5 A supply warning must also be fixed
before treating USB or I2C behavior as reliable.

## Safe commands available now

Run inference with a synthetic level IMU:

```bash
bash onboard/scripts/run-policy-print.sh --imu level --duration-s 5
```

Run inference from the real BNO085 and print all 12 targets:

```bash
bash onboard/scripts/run-policy-print.sh --imu bno085
```

Start the LAN dashboard:

```bash
bash onboard/scripts/run-policy-web.sh --imu bno085
```

Open the URL printed by the command. The default port is 8090. The page can
start and stop inference, change the requested speed from 0 to
0.20 m/s, and show the live IMU plus all 12 motor targets. It cannot open the
servo bus or enable torque.

When using the boot service, open `http://pi5-dog.local:8090/`. The tracked
service configuration does not require a token and should be used only on a
trusted local network.

To run the dashboard automatically after boot:

```bash
bash onboard/scripts/install-policy-web-service.sh --start
sudo systemctl status drobot-policy-web
```

The service is open to the local network by default. Optional token protection
can be enabled later through `/etc/default/drobot-policy-web`.

## Manual inverse-kinematics and crawl dashboard

The existing manual dashboard remains on port 8080. It includes calibrated
per-joint controls, inverse-kinematics-backed stance controls, distributed
crawl, diagonal-pair gait, telemetry, and STOP + DISARM. The intended topology
is:

```text
phone/computer browser
        |
        | Wi-Fi or Ethernet (HTTP now, ROS 2 later)
        v
Raspberry Pi 5 -- USB --> Feetech servo adapter -- servo bus --> 12 servos
        |
        `-- I2C --> BNO085
```

Connect the USB servo adapter to the Pi, not simultaneously to another
computer. Exactly one process must own the serial bus. The manual dashboard can
run without ROS 2. Install and start its safe simulated version with:

```bash
bash onboard/scripts/install-manual-runtime.sh
bash onboard/scripts/install-manual-web-service.sh --start
```

Then open `http://pi5-dog.local:8080/`. The service defaults to demo mode and
cannot command real motors. To enable hardware later, set
`DROBOT_MANUAL_DEMO=false` and the detected `DROBOT_MANUAL_SERIAL_PORT` in
`/etc/default/drobot-manual-web`, then restart the service while the robot is
supported and the physical cutoff is ready.

Keep `DROBOT_MANUAL_FALLBACK_DEMO=false` on the real robot. If the adapter or a
configured motor is missing, the service continues serving hardware diagnostics
with motion disabled and retries recovery during telemetry polling. It enables
controls only after verifying all 12 IDs and disarming them. Linux address reuse
is enabled for this service so an active browser
connection does not prevent port 8080 from reopening during a clean restart;
Windows retains exclusive port ownership for the desktop dashboard. Trusted-LAN
Pi pages do not require a control token. Motion POSTs carry a non-secret client
version so stale pages are told to reload rather than controlling the robot.

Brief browser or Wi-Fi polling failures are shown as a live connection warning
and are not stored in the recent error log. Active hardware and RL faults remain
visible, then clear automatically after the corresponding server state recovers.
Other command errors expire after ten minutes; Settings still provides an
immediate manual clear.

The page sends its heartbeat every 0.7 seconds on an independent request path.
A missing heartbeat or closed page becomes a visible warning after 20 seconds,
but it does not stop the gait, alter targets, or remove torque. The onboard gait
continues until **STOP + DISARM**, an actual controller/bus fault, process
shutdown, or the physical cutoff.

Both walking buttons run continuously until **STOP + DISARM**. Starting a gait
from a minor off-stance pose no longer fails the old zero-centred tolerance
check: the controller holds each measured position first and ramps to the gait
stance. This relaxation does not remove startup ID checks, computed joint-limit
checks, browser-heartbeat diagnostics, telemetry/motion fault handling, or the
physical-cutoff requirement.

Keep `DROBOT_MANUAL_SERIAL_PORT=auto` for replaceable compatible adapters. If
USB reconnect changes the Linux node from `ttyACM0` to `ttyACM1` (or similarly
for `ttyUSB`), the running dashboard closes the dead handle, resolves the new
device, verifies IDs 1-12, and disarms all motors before serving telemetry
again. It refuses partial-bus recovery.

For battery comparisons, disarm all motors, connect the selected source, press
**RESET AT IDLE**, and allow several telemetry samples before walking. Compare
the 60-second power chart, idle-to-load voltage sag, peak current, and possible
stall IDs using the same supported gait. Sag plus stall flags indicates an
electrical-delivery or mechanical-load problem; falling without those signals
is stronger evidence for added battery mass, center-of-mass shift, or contact
geometry. Dashboard watt-hours are sampled servo estimates and exclude the Pi.
The **FULL / GOOD / LOW / RECHARGE** label is a coarse 3S idle-voltage estimate;
use a balance-plug checker to verify each cell before charging or continued use.

The standalone service must be stopped before starting the ROS 2 onboard node:

```bash
sudo systemctl stop drobot-manual-web
```

## Controlled rollout to learned motor control

The port 8080 dashboard now includes the first guarded real-motor rollout. It
uses live calibrated joint position/velocity feedback and the real BNO085 while
keeping the manual dashboard as the only servo-bus owner. The standalone port
8090 service remains print-only and should be stopped before an 8080 RL test.

1. **Sensor validation:** confirm the BNO085 mounting transform and signs while
   the robot is supported. Level projected gravity should be near `[0,0,-1]`.
2. **Live joint feedback:** all 12 calibrated positions and encoder-derived
   velocities feed the observation; stale, missing, or out-of-range feedback
   stops and disarms the test.
3. **Bounded actuation:** the UI permits a supported `1-60 s` test inside the
   selected model's declared speed range (`0.005-0.039 m/s` for V30),
   initializes targets from the measured pose, and enforces joint, elapsed-time
   rate, tilt, and telemetry guards. Normal timed completion returns all
   12 joints to calibrated center and keeps torque holding; an explicit stop or
   policy/hardware fault still disarms. An RL temperature sample from `55-64 C`
   must persist across repeated reads for five seconds before disarm; `65 C` or
   above remains an immediate critical stop.
4. **Floor rollout:** remains future work. Review recorded timing, tracking,
   current, voltage sag, body motion, and support behavior before removing the
   fixture or raising the speed/duration limits.
5. **ROS 2 split:** publish BNO085 data as `sensor_msgs/Imu`, servo feedback as
   `sensor_msgs/JointState`, and velocity commands separately. Publish
   timestamped policy targets to the single motor-owner node, which remains
   responsible for all safety checks.

This split lets the same policy core run from shell scripts today and behind
ROS 2 later, while preventing the browser, manual gait, and learned policy from
fighting over the servo bus.

The exact V1 contract and stop conditions are in
`hardware/test-apps/four-leg-dashboard/specs/rl-walk-v1.md`.

## Verification recorded on 2026-08-21

- Installed the ARM64 policy environment from the repository on the Pi.
- Verified the tracked ONNX model hash.
- Ran the level-IMU print loop successfully.
- Read live BNO085 samples and produced 12 bounded, rate-limited policy targets.
- Confirmed that neither print mode nor the policy dashboard opens a servo port.
- Confirmed that no USB serial servo adapter and no `/opt/ros` installation
  were present at the time of inspection.

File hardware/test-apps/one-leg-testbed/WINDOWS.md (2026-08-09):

# Windows USB setup and first-movement guide

This guide configures and tests one Drobot leg containing three Feetech ST3215
serial bus servos from Windows PowerShell. It covers USB detection, assigning
IDs 1-3, recording the assembled leg's neutral position, reading telemetry,
and making the first small movements.

The software has been checked on Windows without motors connected. The example
joint limits and motor settings are conservative starting values, not
hardware-validated mechanical limits.

## Before connecting a motor

You need:

- Windows 10 or 11;
- 64-bit Python 3.11 or newer;
- a compatible half-duplex Feetech/Waveshare bus-servo USB adapter;
- a data-capable USB cable;
- an external supply appropriate for the exact ST3215 voltage variant;
- a physical servo-power cutoff within reach; and
- a clamp or fixture that prevents the leg from striking the desk.

Do not power three ST3215 servos from the computer's USB port. USB carries the
control connection; the servos require their appropriate external supply.
Follow the adapter manufacturer's instructions for servo power and shared
ground wiring.

Turn external servo power off before connecting, disconnecting, or
daisy-chaining motors. Keep hands away from horns and linkages whenever torque
may be enabled.

## 1. Install the testbed

Open PowerShell in the repository and run:

```powershell
Set-Location hardware\test-apps\one-leg-testbed

py -3.11 -m venv .venv
.\.venv\Scripts\python.exe -m pip install --upgrade pip
.\.venv\Scripts\python.exe -m pip install -e ".[dev]"

Copy-Item .\leg.example.toml .\leg.toml
```

The commands use the virtual environment directly, so PowerShell script
execution policy does not need to be changed and activation is optional.

If `py -3.11` is not found, install a current 64-bit Python release with the
Windows Python launcher, then open a new PowerShell window and confirm:

```powershell
py -3.11 --version
```

## 2. Find the USB adapter

Connect the USB adapter, initially without any servo connected, and run:

```powershell
.\.venv\Scripts\drobot-leg.exe ports
```

The output should include a Windows port such as:

```text
COM5
  USB Serial Port (COM5)
  USB VID:PID=...
```

Use the displayed port in the rest of this guide. Replace `COM5` if Windows
assigned a different number.

If no port appears:

1. Try a known data-capable USB cable and another USB port.
2. Open Device Manager and inspect **Ports (COM & LPT)** and **Other devices**.
3. Install only the driver recommended by the USB adapter manufacturer.
4. Disconnect and reconnect the adapter, then run `drobot-leg ports` again.

Windows can assign a different COM number after changing USB sockets, so list
ports again whenever a previously working port disappears.

## 3. Review the motor map

The local `leg.toml` maps the three physical testbed motors:

| Testbed number | Joint | Bus ID |
| ---: | --- | ---: |
| 1 | hip abduction | 1 |
| 2 | hip flexion | 2 |
| 3 | knee | 3 |

It also defines conservative angle, torque, speed, acceleration, and
per-command movement limits. Keep the initial limits unchanged for the first
unloaded test.

## 4. Assign IDs with one motor connected

New motors may all use ID 1. Never connect multiple factory-default motors
while assigning IDs because identical IDs collide on the shared bus.

Start the guided setup:

```powershell
.\.venv\Scripts\drobot-leg.exe --config .\leg.toml --port COM5 setup-ids
```

For each prompted motor:

1. Turn external servo power off.
2. Connect only the named motor to the adapter.
3. Restore external servo power.
4. Press Enter and type `ASSIGN` when requested.
5. Turn external power off before disconnecting that motor.

The program assigns IDs 1, 2, and 3 according to `leg.toml`. It disables torque
before changing an ID and verifies that the motor responds at the new ID.

To assign one isolated motor manually:

```powershell
.\.venv\Scripts\drobot-leg.exe --config .\leg.toml --port COM5 `
  assign-id --current-id 1 --new-id 2
```

The backtick continues a PowerShell command onto the next line. The same
command can be written on one line without it.

## 5. Connect and scan all three motors

Turn external power off, daisy-chain the three uniquely numbered motors, and
support the leg in its fixture. Restore power and scan:

```powershell
.\.venv\Scripts\drobot-leg.exe --config .\leg.toml --port COM5 `
  scan --id-start 1 --id-end 3
```

Proceed only when exactly IDs 1, 2, and 3 answer. If an ID is missing, power
off and check its cable and previous assignment. If IDs collide, return to the
one-motor assignment procedure.

## 6. Apply conservative position-control settings

With the leg supported:

```powershell
.\.venv\Scripts\drobot-leg.exe --config .\leg.toml --port COM5 configure
```

Review the warning and type `CONFIGURE`. This selects position mode and applies
the configured torque limit and acceleration. All motors remain disarmed when
the command finishes.

## 7. Record the assembled neutral pose

Run:

```powershell
.\.venv\Scripts\drobot-leg.exe --config .\leg.toml --port COM5 `
  --calibration .\calibration.json capture-centers
```

The program disables torque on all three motors. Support the leg, manually
place all joints at the intended neutral pose, and then press Enter. Encoder
centers are stored locally in the ignored `calibration.json`; the procedure
does not write homing offsets to servo EEPROM.

Software commands and telemetry use Feetech signed extended positions when a
calibrated range crosses raw encoder boundary 0/4095, so a boundary crossing
does not by itself require an EEPROM update. To place neutral near the middle
of the conventional single-turn range anyway, keep torque off and the supported
joint physically at neutral, then persistently make that motor logical tick
2048:

```powershell
.\.venv\Scripts\drobot-leg.exe --config .\leg.toml --port COM5 `
  set-middle --motor 1
```

Review the named motor and type `CENTER`. Repeat for another motor only while
the complete leg remains at neutral, then run `capture-centers` again. This
updates the selected servo's internal position correction and is distinct from
the local JSON calibration.

## 8. Check telemetry before moving

```powershell
.\.venv\Scripts\drobot-leg.exe --config .\leg.toml --port COM5 `
  --calibration .\calibration.json status
```

Confirm that all three motors respond and that voltage and temperature look
reasonable for the unpowered-to-powered bench setup. Current feedback is
diagnostic telemetry, not a calibrated measurement of joint torque.

## 9. Make the first small movement

Clamp or suspend the leg, clear the mechanism, and keep the physical power
cutoff within reach:

```powershell
.\.venv\Scripts\drobot-leg.exe --config .\leg.toml --port COM5 `
  --calibration .\calibration.json control
```

The controller starts with all motors disarmed. The prompt always shows the
selected motor number and name:

```text
[#1 hip_abduction]>
```

Try one degree at a time:

```text
select 1
arm
+ 1
status
- 1
disarm

select 2
arm
+ 1
status
disarm

select 3
arm
- 1
status
disarm

disarm-all
quit
```

`arm` first commands the selected motor's measured position and then enables
torque. `set`, `+`, and `-` affect only the selected motor. A previously armed
motor continues holding its last target until explicitly disarmed.

The default configuration rejects targets outside each joint's conservative
range and rejects a target change larger than five degrees. Repeated commands
can still move a joint into a physical obstruction, so watch the mechanism and
use small increments.

If positive motion goes in the wrong physical direction:

1. Run `disarm-all` and `quit`.
2. Turn external servo power off.
3. Change that motor's `direction` in `leg.toml` from `1` to `-1`.
4. Restore power and capture the neutral centers again.
5. Repeat the one-degree unloaded test.

## 10. Use the local browser controller

Reinstall the editable project once so Windows creates the
`drobot-leg-web.exe` entry point:

```powershell
Set-Location hardware\test-apps\one-leg-testbed
.\.venv\Scripts\python.exe -m pip install -e ".[dev]"
```

Start the controller:

```powershell
.\.venv\Scripts\drobot-leg-web.exe --config .\leg.toml --port COM4 `
  --calibration .\calibration.json
```

The program opens `http://127.0.0.1:8765/`. The page shows current and target
angles for all three joints. Check the hardware-ready confirmation, arm one
joint, then use its slider or type an exact destination angle. Destinations
inside the configured joint range are approached smoothly in bounded internal
steps.

The server listens on the local Windows machine only. It automatically disarms
after three seconds without a browser heartbeat, on normal page close, or when
the server receives `Ctrl+C`. Keep the physical external-power cutoff within
reach because software disarm cannot cover every process, USB, operating-system,
or wiring failure.

To check the interface with simulated motors and no serial-port access:

```powershell
.\.venv\Scripts\drobot-leg-web.exe --config .\leg.toml `
  --calibration .\calibration.json --demo
```

## Emergency and normal stopping

For a normal software stop:

```text
disarm-all
quit
```

`Ctrl+C`, `quit`, and normal program exit make a best-effort attempt to disable
every motor armed during that session. They cannot guarantee torque-off after
a USB disconnect, interpreter crash, wiring failure, or operating-system
failure. Use the physical external-power cutoff for an emergency.

## Windows troubleshooting

### Access to COM5 is denied

Close serial terminals, Arduino tools, vendor utilities, or another
`drobot-leg` process using that port. Disconnect and reconnect the adapter if
the previous process exited unexpectedly.

### More than one USB serial adapter is found

Pass the exact port explicitly:

```powershell
.\.venv\Scripts\drobot-leg.exe --config .\leg.toml --port COM5 `
  scan --id-start 1 --id-end 3
```

### The adapter appears, but no motor answers

Power off before inspecting wiring. Check external servo power, adapter mode,
shared ground, connector orientation, data continuity, configured one-megabit
baud rate, and the expected SMS/STS protocol. Do not repeatedly move connectors
while the servo supply is live.

### A motor jumps or approaches a collision

Cut external servo power. Verify that the horn was installed near the intended
neutral position, then repeat neutral capture. Review `direction`, reduce the
joint's configured range, and restart with one-degree changes.

### PowerShell cannot find `drobot-leg.exe`

Confirm installation using the virtual environment's Python:

```powershell
.\.venv\Scripts\python.exe -m pip show drobot-one-leg-testbed
.\.venv\Scripts\python.exe -m drobot_leg_testbed --help
```

## Software-only validation

These checks do not energize or communicate with motors:

```powershell
.\.venv\Scripts\python.exe -m pytest --basetemp .pytest-tmp-windows
.\.venv\Scripts\python.exe -m ruff check .
.\.venv\Scripts\python.exe -m ruff format --check src tests
.\.venv\Scripts\python.exe -m compileall -q src tests
```

Passing these checks confirms the software contracts, not the mechanical
limits, power integrity, thermal behavior, or safety of the physical leg.

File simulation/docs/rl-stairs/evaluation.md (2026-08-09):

# Evaluating the stair policy

## Current evidence

As of 2026-07-27, deterministic model reload, manifest verification, two
level-1 evaluation episodes, loaded PPO algorithm verification, screenshot
capture, and one H.264 recording have passed as pipeline checks. The corrected
512-step smoke checkpoint achieved `0/2` evaluation success, `0/1` recording
success, and never reached the first stair. The v1 full run was stopped at
964,608 steps after its 950k checkpoint also reached step `0` in all five
level-1 audit episodes. Do not substitute either the successful flat-walking
result or the successful smoke pipeline for stair-climbing evidence. The
replacement experiment is documented under
[`docs/rl-stairs-v2/`](../rl-stairs-v2/README.md).

Evaluate a stair checkpoint only after:

1. generating the stair world;
2. completing the pipeline smoke test;
3. training a separate 57-input stair model;
4. retaining the model's adjacent `.contract.json`.

All commands below run from the repository root.

## Recorded level-1 smoke evaluation — 2026-07-27

The tested command was:

```powershell
& C:\isaacsim\python.bat simulation\isaac\rl\stairs\evaluate_stairs_ppo.py `
  --model simulation\isaac\output\rl\ppo-stairs-v1-smoke\drobot_stairs_ppo_final.zip `
  --episodes 2 `
  --active-steps 1 `
  --screenshot reviews\ppo-stairs-v1-smoke.png `
  --report simulation\isaac\output\rl\ppo-stairs-v1-smoke\evaluation_report.json
```

The evaluator, schema-2 manifest verification, and direct loaded-PPO algorithm
verification all reported PASS. The behavioral result did not:

| Metric | Result |
| --- | ---: |
| Seed | `143` |
| Stair success | `0/2` |
| Mean highest step | `0.0` |
| Episode lengths | `188`, `114` steps |
| Mean forward displacement | `0.322017 m` |
| Mean elevation gain | `-0.137918 m` |
| Mean return | `162.266386` |
| Worst minimum base clearance | `0.219377 m` |
| Worst maximum body tilt | `47.457092 degrees` |
| Screenshot bytes | `449,249` |

Both episodes ended with `body_tipped`, after 188 steps (3.133 seconds) and
114 steps (1.900 seconds). This proves deterministic checkpoint loading,
57-input inference, two physics updates per control action, schema-2
dependency/algorithm checking, episode reporting, and screenshot capture. It
is explicit evidence that the smoke model is not a stair policy.

## Staged deterministic evaluation

The evaluator uses `model.predict(..., deterministic=True)`. `--active-steps`
pins the requested curriculum goal instead of using training progress. Start
with each level separately so a full-stair failure is diagnosable.

### Level 1

```powershell
& C:\isaacsim\python.bat simulation\isaac\rl\stairs\evaluate_stairs_ppo.py `
  --model simulation\isaac\output\rl\ppo-stairs-v1\drobot_stairs_ppo_final.zip `
  --active-steps 1 `
  --episodes 10 `
  --seed 143 `
  --report simulation\isaac\output\rl\ppo-stairs-v1\evaluation-level-1.json
```

Repeat with levels 2 and 3:

```powershell
& C:\isaacsim\python.bat simulation\isaac\rl\stairs\evaluate_stairs_ppo.py `
  --model simulation\isaac\output\rl\ppo-stairs-v1\drobot_stairs_ppo_final.zip `
  --active-steps 2 `
  --episodes 10 `
  --seed 143 `
  --report simulation\isaac\output\rl\ppo-stairs-v1\evaluation-level-2.json

& C:\isaacsim\python.bat simulation\isaac\rl\stairs\evaluate_stairs_ppo.py `
  --model simulation\isaac\output\rl\ppo-stairs-v1\drobot_stairs_ppo_final.zip `
  --active-steps 3 `
  --episodes 10 `
  --seed 143 `
  --report simulation\isaac\output\rl\ppo-stairs-v1\evaluation-level-3.json
```

### Full four-step evaluation

Use more episodes for the acceptance run:

```powershell
& C:\isaacsim\python.bat simulation\isaac\rl\stairs\evaluate_stairs_ppo.py `
  --model simulation\isaac\output\rl\ppo-stairs-v1\drobot_stairs_ppo_final.zip `
  --active-steps 4 `
  --episodes 20 `
  --seed 143 `
  --report simulation\isaac\output\rl\ppo-stairs-v1\evaluation-report-20ep.json
```

The default `--active-steps` is all four. The explicit argument above makes
the review record unambiguous. Run additional seed streams rather than
reporting one favorable seed:

```powershell
& C:\isaacsim\python.bat simulation\isaac\rl\stairs\evaluate_stairs_ppo.py `
  --model simulation\isaac\output\rl\ppo-stairs-v1\drobot_stairs_ppo_final.zip `
  --active-steps 4 `
  --episodes 20 `
  --seed 1143 `
  --report simulation\isaac\output\rl\ppo-stairs-v1\evaluation-report-seed-1143.json
```

Evaluation refuses a missing or mismatched manifest. The
`--allow-unverified-model` option should be reserved for documented recovery;
it weakens provenance and is not acceptable for a policy-comparison result.
With a verified manifest, the evaluator also compares the loaded PPO object
against the saved algorithm contract; a renamed ZIP with incompatible
architecture or hyperparameters does not pass.

## Visual inspection and screenshot

Watch one deterministic episode with the fixed external view and save a PNG:

```powershell
& C:\isaacsim\python.bat simulation\isaac\rl\stairs\evaluate_stairs_ppo.py `
  --model simulation\isaac\output\rl\ppo-stairs-v1\drobot_stairs_ppo_final.zip `
  --active-steps 4 `
  --episodes 1 `
  --seed 143 `
  --gui `
  --camera-view external `
  --screenshot reviews\ppo-stairs-v1-evaluation.png `
  --report simulation\isaac\output\rl\ppo-stairs-v1\evaluation-visual.json
```

Use `--camera-view onboard` to inspect the mounted camera. Camera images are
for review only; the version-1 policy does not consume pixels.

During visual review, look for:

- body or legs colliding with riser faces;
- feet slipping sideways or walking near the stair edge;
- a ballistic hop that satisfies the goal but is not repeatable climbing;
- oscillation while holding the top-platform goal;
- foot tunneling, interpenetration, or visibly unstable contact;
- the base clearing each local tread with useful margin;
- cables, covers, or printed geometry that the current collision model omits.

## Record one deterministic run

The recorder captures a single episode as H.264 MP4 using an offscreen RTX
camera. At the defaults, it writes `960 × 540` at 30 FPS. Because control runs
at 60 Hz, it records every second policy step. A timeout-length episode can be
up to 22 seconds and 660 frames.

```powershell
& C:\isaacsim\python.bat simulation\isaac\rl\stairs\record_stairs_ppo.py `
  --model simulation\isaac\output\rl\ppo-stairs-v1\drobot_stairs_ppo_final.zip `
  --active-steps 4 `
  --seed 143 `
  --camera-view external `
  --video reviews\ppo-stairs-v1-evaluation.mp4 `
  --thumbnail reviews\ppo-stairs-v1-evaluation.png `
  --report simulation\isaac\output\rl\ppo-stairs-v1\recording_report.json
```

Expected outputs:

- `reviews/ppo-stairs-v1-evaluation.mp4`;
- `reviews/ppo-stairs-v1-evaluation.png`;
- `simulation/isaac/output/rl/ppo-stairs-v1/recording_report.json`.

The report must say `"status": "PASS"` and record nonzero
`recorded_frames`, `video_bytes`, and `thumbnail_bytes`. It also stores the
episode metrics and model-contract verification. A playable video is review
evidence for one seeded episode, not a substitute for multi-episode metrics.

The requested FPS must divide the configured 60 Hz control rate exactly.

### Recorded level-1 smoke recording — 2026-07-27

The smoke checkpoint was recorded with this command:

```powershell
& C:\isaacsim\python.bat simulation\isaac\rl\stairs\record_stairs_ppo.py `
  --model simulation\isaac\output\rl\ppo-stairs-v1-smoke\drobot_stairs_ppo_final.zip `
  --active-steps 1 `
  --video reviews\ppo-stairs-v1-smoke.mp4 `
  --thumbnail reviews\ppo-stairs-v1-smoke-recording.png `
  --report simulation\isaac\output\rl\ppo-stairs-v1-smoke\recording_report.json
```

The recorder, schema-2 model-manifest verification, and direct loaded-PPO
algorithm verification all reported PASS:

- seed `143`, active level `1`;
- 660 frames at `960 × 540`, 30 FPS, H.264 MP4;
- `reviews/ppo-stairs-v1-smoke.mp4`: 14,730,825 bytes;
- `reviews/ppo-stairs-v1-smoke-recording.png`: 174,296 bytes;
- `simulation/isaac/output/rl/ppo-stairs-v1-smoke/recording_report.json`
  preserves the runtime contract and episode metrics.

The episode timed out after 22.0 seconds, reached highest step `0`, and did not
complete the level. It moved `0.542857 m` forward while remaining on the
approach. The PASS status validates deterministic inference, dependency and
algorithm contract checking, offscreen RTX capture, thumbnail output, and
H.264 encoding. It does not indicate stair competence.

## Evaluation report fields

Each completed episode records:

| Field | Interpretation |
| --- | --- |
| `stairs_completed` | Held the configured goal for 0.5 seconds without failure |
| `active_step_count` | Requested curriculum level |
| `highest_step_reached` | Highest analytic tread index reached, 0–4 |
| `return` | Sum of shaped rewards; useful only with physical metrics |
| `length_steps`, `duration_s` | Time to success/failure or the 22-second truncation |
| `forward_displacement_m` | Final X minus reset X |
| `lateral_displacement_m` | Final Y minus reset Y |
| `elevation_gain_m` | Final base Z minus reset base Z |
| `final_terrain_height_m` | Analytic surface under the final base X |
| `minimum_base_clearance_m` | Worst local clearance during the episode |
| `maximum_body_tilt_deg` | Worst tilt from projected gravity |
| `goal_hold_duration_s` | Consecutive time held beyond the goal |
| `failure_reasons` | Exact low-clearance, tip, corridor, or backward causes |
| `terminated`, `truncated` | Whether an outcome ended the episode or time expired |

The aggregate report includes `success_count`, `success_rate`, failure reason
counts, mean return, mean highest step, mean forward displacement, mean
elevation gain, worst minimum clearance, and worst maximum tilt.

## How to interpret results

- `success_rate` is the primary completion metric. Report its numerator,
  denominator, seed, active-step level, and model hash.
- Mean `highest_step_reached` shows partial progress when success is still
  zero. Break it down by episode; a mean can hide bimodal behavior.
- Full-stair success should end on terrain height `0.16 m` and normally show
  positive elevation gain. A strange combination can reveal a geometry or
  reward exploit.
- Forward displacement alone is insufficient because the approach is over a
  meter long.
- High return with low success means shaping terms are masking task failure.
- Many 22-second truncations with no failure can mean stable stalling at a
  riser.
- `base_clearance_too_low` points to body/riser contact or collapse.
- `body_tipped` points to unstable posture or aggressive ascent.
- `left_stair_corridor` means `|world Y| > 0.48 m`; review whether inherited
  flat-policy drift is being transferred.
- `moved_too_far_backward` means world X fell below `-1.20 m`.
- Minimum clearance just above `0.20 m` and tilt just below `45.6 degrees`
  technically pass but provide little robustness margin.

Compare checkpoints using identical config, world, composed-dependency, and
PPO algorithm contracts, plus the same active level, episode count, and seed
streams. If any of those differ, treat the runs as different experiments.

## Suggested simulation acceptance gate

Before describing a checkpoint as a useful **simulated stair policy**, record:

- successful contract verification;
- multiple independent evaluation seed streams;
- high completion at levels 1, 2, 3, and 4;
- no non-finite state;
- low failure and timeout rates;
- consistent positive elevation onto the `0.16 m` platform;
- acceptable lateral displacement and no corridor exits;
- clearance and tilt comfortably inside termination thresholds;
- a visually reviewed external recording with plausible contacts;
- no reliance on a single unusually favorable checkpoint or seed.

No numeric success threshold has yet been approved for this experiment.
Choose and document one before final model selection rather than after seeing
the results.

## Sim-to-real assumptions and limitations

Passing the simulation gate does not authorize hardware stair tests.

- The policy receives an exact analytic terrain profile from simulator world
  X. Hardware has no equivalent sensor pipeline yet.
- The staircase is one fixed profile: four `40 mm` risers and `230 mm`
  treads. Stair dimensions, edge shape, approach angle, and landing are not
  randomized.
- Friction, foot compliance, link mass/inertia, backlash, battery voltage,
  torque/thermal derating, control latency, packet loss, and IMU/encoder noise
  are not randomized here.
- The reset always begins on flat ground in a narrow pose range.
- The observation has no foot-contact sensors and no image/depth features.
- The task teaches ascent only. It does not test descent, turning on stairs,
  damaged feet, payload changes, or interrupted recovery.
- The collision proxies and contact material approximate, but do not fully
  reproduce, printed hardware and household stairs.
- One direct Isaac environment is used rather than many randomized Isaac Lab
  clones, increasing wall-clock time and overfitting risk.

Before hardware, replace or reproduce the terrain inputs with a documented
perception/state-estimation contract, add relevant randomization, test
latency and actuator limits, and verify inference timing. First physical
motion should be suspended or guarded with a human-operated emergency stop.
Only after stable guarded flat-floor tests should the robot approach a low
single step with fall protection; a four-step staircase is a later safety
stage.

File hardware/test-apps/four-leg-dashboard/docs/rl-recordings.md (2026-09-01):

# RL real-walk recordings

The hardware dashboard automatically starts a recording whenever an RL walk
starts. Recording does not open the servo bus and does not perform additional
IMU or encoder reads. It observes the same synchronized values already used by
the 60 Hz policy loop and places them on a bounded in-memory queue. A separate
writer thread performs all JSON and filesystem work.

If storage cannot keep up, the control loop drops recording items rather than
waiting. `metadata.json` reports `dropped_samples` and `dropped_events`; do not
use an incomplete trial for timing-sensitive analysis without accounting for
those gaps. A recorder failure is shown in the RL recorder status but does not
alter motor-control behavior.

## Storage and dashboard controls

The default directory on the Raspberry Pi is:

```text
~/.local/share/drobot2/rl-recordings
```

Override it when starting the dashboard with:

```bash
drobot-four-leg-web --recordings-dir /path/to/recordings ...
```

Open **Settings → Trial recordings** on port 8080 to refresh the list, assign a
human-readable name, download a ZIP, or delete a finalized trial. A trial is
listed as `FINALIZING` briefly while the background writer drains its queue and
builds the archive. Folder IDs never change when a display name is edited.

Each trial folder and ZIP contains:

- `metadata.json`: schema version, result, timestamps, command, model and
  hardware-file hashes, sensor configuration, counts, and drop statistics;
- `samples.jsonl`: one object for each successfully commanded policy step;
- `events.jsonl`: start/finalization events and staggered full motor diagnostics.

New recordings store the measured 3.175 kg total robot mass plus the V20
simulation payload estimate: a 523.18 g battery/holder centered at
`[-0.1315, 0, 0.05] m` in the body frame. The payload number combines the
measured 416 g battery with CAD-derived box/lid mass; fasteners, foam, and wire
remain uncertain. Keep that distinction when fitting simulation dynamics.
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

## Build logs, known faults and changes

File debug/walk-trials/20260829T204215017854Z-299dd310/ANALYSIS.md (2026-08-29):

# V20 real-walk trial 20260829T204215017854Z-299dd310

## Conclusion

This trial clears the previously suspected Raspberry Pi scheduling problem but
exposes three larger control-contract mismatches. The most important is the
startup pose: the dashboard requires all twelve joints at calibrated zero,
while V20 was trained from a crouched neutral pose with the hip-flexion and
knee joints at approximately `+/-30 degrees`. The policy therefore begins from
an observation about 30 degrees outside its nominal state and immediately
tries to enter the crouch while its 1.25 Hz gait clock is already moving.

The second mismatch is target dynamics. Training permits approximately 4.38
degrees of target motion per 60 Hz step, while the physical runtime now permits
at most 2 degrees per step. Even after the 1.2-second startup interval, the
policy remains ahead of the limiter on several hip-flexion and knee joints, and
the loaded hardware then trails the limited targets further.

The third issue is gait choice. V20 is a fixed-cadence diagonal-pair trot with a
65% duty factor. It is not a slow, three-support-leg crawl. The user's stable
hardcoded crawl provides strong evidence that a sequential learned crawl is a
better target for this heavy, rear-loaded robot than trying to make the current
trot arbitrarily slow.

Do not raise the real-hardware target-step cap or silently slow V20's gait
clock. Both would change the dynamics seen by a policy that was not trained for
them. Correct the RL startup stance first, then train a deployment-matched
low-speed policy.

## Repository artifacts and privacy processing

This directory contains:

- `20260829T204215017854Z-299dd310.zip`: the original automatic controller
  recording;
- `IMG_0834.MOV`: a repository-safe copy containing only the HEVC picture and
  primary AAC audio;
- `video-contact-sheet.jpg`: one-frame-per-second overview;
- `rl-motion-contact-sheet.jpg`: four-frame-per-second view around the RL run;
- `analyze_trial.mjs`: dependency-free numerical analysis of an extracted
  recording; and
- `analysis-metrics.json`: reproducible full-precision results from that script.

The source phone file contained precise QuickTime location, location accuracy,
device, software, timestamp, positional-audio, and timed-metadata tracks. The
repository copy was stream-copied with all global metadata and chapters removed
and only stream 0 (video) plus the primary audio stream retained. A second
FFprobe inspection found two streams only and no location, device, or creation
metadata. The original attachment was not modified.

The extracted JSON telemetry was also scanned for GPS/location fields, local IP
addresses, SSIDs, passwords, and tokens; none were found. The archive's normal
Raspberry Pi repository paths under `/home/rd/drobot2` are retained.

SHA-256:

| Artifact | SHA-256 |
| --- | --- |
| Sanitized `IMG_0834.MOV` | `f45d2262fb5c2fcaf69f5859a6b41b77cbbd68020371f3e5b6bc1ec85d6bd40f` |
| Recording ZIP | `99ecb1fb4fcccf6ba43e981006672d2aa20024d7840b8f23e4df6dfde8edcc06` |

The phone recording began at `20:42:10Z`. Controller recording began at
`20:42:15.017854Z` and ended at `20:42:20.023017Z`, so the internal trial maps
to approximately 5.018 through 10.023 seconds in the video.

## Trial identity

| Item | Value |
| --- | ---: |
| Model | V20 `model_900.onnx` |
| Model SHA-256 | `f787669d33115f117ac691c1ba7bb145fa6a726c6a5d22aec7aecc9e284d6529` |
| Requested command | `0.04 m/s` forward, zero lateral/yaw |
| Duration | `5.0 s` |
| Samples | `300` |
| Gait clock | fixed `1.25 Hz` / `0.8 s` period |
| Clock cycles during trial | `6.25` |
| Recorded total robot mass | `3.175 kg` |
| Rear payload model | `0.52318 kg` at `[-0.1315, 0, 0.05] m` |
| Result | completed, no software fault |

## What the controller fixes accomplished

The real-time loop is no longer the leading explanation for this walk:

| Signal | This trial | Earlier baseline |
| --- | ---: | ---: |
| Achieved policy rate | `60.10 Hz` | nominal average `60 Hz` |
| Policy interval p50 / p95 / max | `16.76 / 20.16 / 22.62 ms` | p95 about `34 ms` |
| Intervals below 10 ms | `1` | `93` |
| Intervals above 25 ms | `0` | `85` |
| Missed deadlines | `0` | catch-up behavior present |
| Distinct joint feedback | `299` samples / `59.92 Hz` | about `15.1 Hz` |
| Joint sample age p95 | `10.77 ms` | synchronous blocking path |
| Dropped samples / events | `0 / 0` | `0 / 0` |

The corrected scheduler, background encoder feedback, and synchronized writes
are working. Feedback did not reach the requested 100 Hz, but approximately 60
Hz with a 10.8 ms p95 age is sufficient to show that the observed gait failure
is not another 15 Hz feedback or catch-up-burst problem.

Sparse round-robin diagnostics reported `11.6-12.0 V`, `33-41 C`, and a maximum
sampled current of `429 mA`. They show no voltage collapse or thermal event in
this five-second run. They are too sparse to rule out short current peaks, but
power is not the primary explanation for this trial.

## Startup-pose mismatch

The simulation reset pose is:

- all hip-abduction joints: `0 degrees`;
- front hip flexion / knees: `+30 / -30 degrees`;
- rear hip flexion / knees: `-30 / +30 degrees`; and
- reset joint noise: only `+/-0.015 rad`, or about `+/-0.86 degrees`.

The recording begins with every real joint within 0.4 degrees of calibrated
zero. The flexion/knee state is therefore roughly 35 reset-noise widths away
from training. The first inference illustrates the consequence:

| Joint group | Initial measured | First policy request | First limited command |
| --- | ---: | ---: | ---: |
| Front hip flexion | about `0 degrees` | about `+30 degrees` | about `+2 degrees` |
| Rear hip flexion | about `0 degrees` | about `-30 degrees` | about `-2 degrees` |
| Front-left knee | `-0.4 degrees` | `-30.0 degrees` | `-2.4 degrees` |
| Rear-left knee | `0.0 degrees` | `+14.9 degrees` | `+2.0 degrees` |
| Front-right knee | `0.0 degrees` | `-47.8 degrees` | `-2.0 degrees` |
| Rear-right knee | `+0.3 degrees` | `+9.1 degrees` | `+2.3 degrees` |

The asymmetric knee requests are not a motor-direction error: they are the
model's response to an out-of-distribution initial observation. The video shows
the matching behavior as the body drops into a crouch and starts stepping at
the same time.

The dashboard should replace **CENTER ALL 12 is RL-ready** with a distinct
**PREPARE RL STANCE** operation. It should move all joints together from center
to the model-declared neutral pose, wait until feedback is close and settled,
then reset action history and gait phase before starting inference. The neutral
pose belongs in model metadata rather than being duplicated in UI code.

## Target tracking and policy behavior

Training and deployment currently use different target slew limits:

- Isaac environment: `4.5836625 rad/s`, approximately `262.6 deg/s` or `4.38
  degrees` per 60 Hz action;
- physical runtime: at most `2 degrees` per update, approximately `120 deg/s`
  at a steady 60 Hz.

Across 285 of 300 samples, at least one raw policy target was more than 2
degrees ahead of the limited target. This is not only startup. After the
training profile's 1.2-second gait ramp, the limiter gap exceeded 2 degrees on
39-47% of hip-flexion samples and 41-55% of knee samples for several joints.

Steady-period p95 target-to-measured errors were:

| Group | p95 absolute error range | Estimated target-following lag |
| --- | ---: | ---: |
| Hip abduction | `6.6-10.4 degrees` | `167-200 ms` |
| Hip flexion | `9.8-27.4 degrees` | `200-333 ms` |
| Knee | `16.9-35.1 degrees` | `300-367 ms` |

The lag estimate is a periodic cross-correlation diagnostic, not a pure motor
transport delay. It combines the servo, mechanical load, target limiter, and
closed-loop policy response. Nevertheless, correlations of `0.80-0.94` show a
consistent delayed version of the commanded gait rather than random encoder
noise.

The policy also spends substantial time at its normalized action boundary:

- front-right hip abduction: `50.7%` of samples at `|action| >= 0.95`;
- rear-left hip abduction: `27.7%`;
- front-left knee: `31.0%`; and
- rear-left knee: `36.7%`.

That asymmetric saturation with zero lateral/yaw command is evidence that V20
is fighting the real state instead of executing a comfortable nominal gait.
The V20 simulator report had already accepted some residual lateral drift; the
real startup and actuator mismatches amplify it.

## IMU and video evidence

The synchronized video shows repeated body rocking and heading oscillation,
not a single clean turn. The internal measurements agree:

| Measurement | Result |
| --- | ---: |
| Roll range | `-5.05` to `+3.07 degrees` |
| Pitch range | `-2.89` to `+7.63 degrees` |
| Absolute yaw-rate p95 / max | `1.073 / 1.422 rad/s` |
| Integrated net yaw | about `+0.4 degrees` |
| Integrated absolute yaw travel | about `137.8 degrees` |
| Accelerometer norm p95 / max | `13.06 / 18.47 m/s2` |
| Consecutive acceleration-vector change p95 | `4.05 m/s2` |

Near-zero net yaw with very large absolute yaw travel is the numerical signature
of the visible left-right wobble. The robot did not simply choose the wrong
heading; it repeatedly corrected past it.

## Recommended implementation order

### 1. Correct deployment startup before another model judgment

Add a model-specific RL-ready stance and a two-stage start:

1. arm and hold calibrated center;
2. smoothly move to the metadata-declared V20 neutral pose at a conservative
   all-joint rate;
3. require measured position near that pose and low measured joint velocity for
   a short settling interval;
4. reset policy action history and phase to zero; and
5. start the timed policy run.

Keep normal completion's smooth return to calibrated center and torque hold.
Keep the 2-degree hardware cap for now; raising it would make this already-fast
trial more violent. Repeat only a short supported V20 trial after the startup
fix. That isolates startup from retraining.

### 2. Make the training actuator contract match deployment

For the next policy, separate the physical servo velocity used in observations
from the target slew limit. Train with the actual `2 degrees / 60 Hz` target
cap, and penalize the gap between the policy-requested target and the processed
target so the network learns executable commands.

Use controlled real pose sweeps to estimate unloaded and loaded response before
choosing simulated actuator delay/gain distributions. The correlations above
are useful bounds but should not be copied directly as a pure 200-350 ms delay.
Randomize torque/voltage capability, actuator response, sensor age, shoe
friction, payload mass, and rear COM within measured ranges.

### 3. Replace fixed-cadence V20 at low speed

The existing V21 profile already maps `0.005-0.10 m/s` to `0.35-1.25 Hz`. At a
`0.04 m/s` command it would use about `0.682 Hz` (a `1.47 s` period) and about a
`32.4 mm` reference stride, instead of V20's `1.25 Hz`, `0.8 s` period, and
55 mm reference stride. This is directionally correct, but V21 still inherits
the diagonal-pair trot.

For the user's smoothness-first goal, train and compare a sequential crawl
candidate using the now-successful hardcoded order:

1. rear right;
2. front right;
3. rear left; and
4. front left.

Use quarter-cycle offsets and a duty factor high enough that normally only one
foot swings while the other three remain support candidates. Replace the
diagonal-sync objective with three-support/contact-margin objectives. Retain
straightness, yaw-rate, body-tilt, action-rate, action-acceleration, joint/body
acceleration, slip, and touchdown penalties. Speed should remain secondary.

### 4. Gate deployment on real-contract metrics

Do not select a checkpoint only because it survives in Isaac. A candidate
should be rejected if it exhibits persistent action saturation, large
requested-to-applied target gaps, excessive tracking lag, yaw oscillation, or
two-leg support behavior inconsistent with the chosen crawl contract. Run the
same metrics at `0.005`, `0.01`, `0.02`, and `0.04 m/s`, then begin physical
evaluation with a stationary RL-stance hold followed by a short supported run.

## Current change and verification status

The follow-up implementation replaces the zero-centered RL start interlock with
a model-declared **PREPARE RL STANCE** operation. V20 metadata now carries its
actual `+/-30 degree` flexion/knee neutral, action scales, 45 deg/s preparation
ramp, 0.5-second settle, five-degree measured-position tolerance, and two-degree
packet cap. Start also requires one synchronized all-motor feedback sample with
low encoder speed. The policy observation and output conversion use the same
metadata rather than duplicated constants.

The new V22 training profile implements the recommended deployment-matched
residual crawl. It uses the exact stable distributed-push RR -> FR -> RL -> FL
hardware sequence as its base target and limits PPO to a 25% correction around
that sequence. Cadence is 0.06-0.30 Hz for `0.003-0.015 m/s` commands, the full
50 mm step remains available at low speed, and target slew is exactly 120 deg/s
(`2 degrees / 60 Hz`). Reward terms favor three-foot support and balanced
four-leg participation while penalizing excess airborne feet, target-limiter
backlog, acceleration, slip, touchdown, tilt, yaw, and lateral motion. The
exported metadata carries the same reference table so the Pi does not mistake
the learned residual for a complete joint target. Training/evaluation results
and deployment status are documented separately after qualification; this
report remains the immutable before-fix trial analysis.

## Qualification outcome

The final V22 formulation uses the distributed crawl as a deterministic base
and learns only a 25%-scale residual. A fresh 1,000-iteration run completed,
and checkpoint 500 was selected over checkpoints 750 and 999 because it was
smoother and drifted less at the same command. Across three 30-second episodes
at each of `0.003`, `0.005`, `0.010`, and `0.015 m/s`, it had zero falls,
zero stalls, zero action saturation, and touchdowns from all four legs. Joint
RMS acceleration ranged from `4.29` to `8.36 rad/s2`, compared with about
`14.39 rad/s2` for the selected V20 simulation checkpoint. Three-or-four-foot
support ranged from `96.3%` at the minimum command to `80.2%` at the maximum.

The full training search, rejected formulations, exact metrics, selected
artifacts, and disclosed low-speed overshoot are in
`simulation/docs/rl-low-speed-residual-crawl-v22.md`. The new Isaac result is a
qualified commissioning candidate, not proof of real-floor stability; the
first physical trial should remain supported at `0.003 m/s` and be reviewed
with the automatic IMU/joint recording.

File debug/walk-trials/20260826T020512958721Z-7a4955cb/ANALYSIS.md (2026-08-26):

# Wobbly-walk baseline 20260826T020512958721Z-7a4955cb

## Purpose and artifacts

This folder keeps the trial evidence in repository-safe form:

- `20260826T020512958721Z-7a4955cb.zip`: automatic dashboard recording, with
  Raspberry Pi absolute paths normalized to repository-relative paths;
- `IMG_0827.MOV`: corresponding phone video, stream-copied without its GPS,
  device, timestamp, or Core Media metadata/data tracks; and
- this report: analysis, controller findings, and the planned comparison.

The trial ran V20 `model_900.onnx` for 10 seconds with a `0.03 m/s`
forward command. The archive says the run completed without a software fault,
contains 600 samples and 78 diagnostic events, and dropped no samples or
events. The numerical samples and diagnostic events were not altered during
privacy sanitization. The phone video is 15.13 seconds at 30 fps and begins approximately
1.96 seconds before the controller recording. FFmpeg 9.0.1 was installed and
used to inspect the MOV metadata and extract review frames.

This is a useful **before-fix baseline**, but it is not a valid judgment of the
trained V20 operating point: V20 was trained from `0.04` through `0.10 m/s`,
while this trial requested `0.03 m/s` and still supplied the model's fixed
1.25 Hz gait clock.

## What the evidence shows

| Signal | Observation | Interpretation |
| --- | ---: | --- |
| Policy rows | 600 / 10 s | The recorder received the requested 60 Hz average row count. |
| Long policy intervals | 85 above 25 ms | Slow operations frequently delayed the nominal 16.7 ms loop. |
| Compressed intervals | 93 below 10 ms | The old deadline loop replayed iterations to catch up after delays. |
| Policy interval p95 | about 34 ms | Timing was not a steady 60 Hz even though the average was 60 Hz. |
| Distinct encoder samples | about 151 / 10 s | Physical joint feedback was only about 15.1 Hz in this software path. |
| Motor-output worker | 20 Hz | Desired policy targets were physically transmitted much more slowly than inference. |
| Gait clock | fixed 1.25 Hz | Cadence did not decrease with the very small forward command. |
| Hip tracking error p95 | about 27 degrees | Multiple joints could not follow the rapidly changing requested gait. |
| Knee tracking error p95 | about 30–37.5 degrees | Large lag was visible in both the internal data and the unstable video. |
| Sent-target rate p95 | up to about 795 deg/s | Fixed-per-call limiting plus catch-up iterations compressed changes in wall time. |
| Front-right abduction saturation | 50.7% of policy outputs | The policy was often at its action boundary and materially asymmetric. |
| IMU pitch | maximum about 13.3 degrees | The body pitched substantially during the short run. |
| IMU roll | about -6.1 to +6.1 degrees | The recorded side-to-side wobble is present in the internal signal. |
| IMU yaw rate | maximum about 2.11 rad/s | The trial contains strong heading disturbance despite a zero-yaw command. |
| Servo voltage | 11.5–11.9 V | Sparse diagnostics do not show a sustained voltage-collapse explanation. |
| Servo temperature | 31–36 C | No thermal event explains this trial. |

The video review sampled 100 frames across the recorded motion and detected the
body AprilTag in all 100. The tag is useful for later camera-pose estimation,
but this clip has no fixed ground tag or calibrated camera, so this report does
not claim metrically accurate world displacement from video alone.

## STS3215 feedback-rate correction

The observed 15.1 Hz is **not an STS3215 specification limit**. The
[manufacturer datasheet](https://files.seeedstudio.com/products/Feetech/108090023_STS3215-C001_Datasheet.pdf)
specifies a maximum position update interval of 1 ms and a default 1 Mbps
communication rate. The
[Feetech communication protocol](https://files.seeedstudio.com/wiki/robotics/Actuator/feetech/Communication_Protocol_Manual.pdf)
defines the position feedback starting at address 56 and the protocol's group
operations.

At 1 Mbps, an isolated eight-byte request plus eight-byte response occupies
roughly 160 microseconds of wire time because UART sends about ten bits per
byte. Turnaround, servo return delay, operating-system scheduling, the USB
adapter, and twelve separate request/response cycles add overhead. Even so,
15 Hz is a result of the previous synchronous multi-servo software path, not
the servo's fresh-data capability.

The controller now asks the SDK for one group position/speed read covering
registers 56–59 for all 12 IDs, with a sequential fallback after communication
failures. It also uses one group write for all targets so the four legs receive
the same command packet. The requested background feedback rate is 100 Hz; the
actual achieved rate must be measured on the Raspberry Pi and USB adapter after
deployment. No persistent servo return-delay register is changed by this work.

## Root causes addressed before retraining

1. **Invocation-count rate limiting.** The old policy limiter allowed one
   fixed 60 Hz-sized target step each time the loop function ran. Catch-up
   calls therefore advanced several target steps in only a few milliseconds.
2. **Catch-up bursts.** A late inference/read iteration left the next deadline
   in the past, causing immediate subsequent iterations instead of dropping the
   missed slot.
3. **Synchronous encoder reads in inference.** Reading physical feedback could
   block observation construction and inference.
4. **Different policy and motor rates.** Policy targets were generated at 60 Hz
   but the dashboard motion worker sent physical targets at 20 Hz.
5. **Sequential leg commands.** Twelve writes introduced an avoidable time skew
   between the first and last leg command.
6. **Unsupported command/cadence pair.** V20 received `0.03 m/s`, below its
   training range, while its clock continued at 1.25 Hz.

## Implemented controller changes

- The policy target limiter uses actual elapsed monotonic time and also caps a
  single delayed update at 5 degrees.
- Both policy and motor-output schedulers skip missed slots; neither replays a
  catch-up burst.
- Encoder polling runs in a background source. Inference consumes the latest
  complete cached sample and faults only when it becomes older than 120 ms.
- The RL motor-output worker runs at 60 Hz; the manual crawl keeps its existing
  slower worker rate.
- Position/speed feedback uses the SDK group-read path first, while full
  voltage/current/temperature diagnostics remain slower and round-robin.
- All pending servo targets are sent in one SDK synchronous write, aligning the
  start of motion across all four legs.
- New recordings add elapsed target time, cumulative missed deadlines, gait
  frequency, feedback-transport mode, the measured 3.175 kg robot mass, and the
  modeled external rear payload metadata.
- V20 metadata now explicitly declares a fixed 0.8-second gait period and a
  supported `0.04–0.10 m/s` command range. The UI follows that model metadata
  instead of offering an untrained `0.03 m/s` value.

## V21 low-speed retraining design

The new `low-speed-external-rear-payload` profile is deliberately separate
from V20. It bootstraps the selected `model_900.pt` weights but resets the new
command curriculum:

- initial command range: `0.04–0.10 m/s`;
- final command range: `0.005–0.10 m/s`;
- curriculum: 38,400 policy steps (600 PPO rollouts at 64 steps each);
- cadence: linearly scaled from 0.35 Hz at `0.005 m/s` to 1.25 Hz at
  `0.10 m/s`;
- stride: scaled from 35% to 100% of the 55 mm reference stride;
- standstill deadband: `0.002 m/s`; and
- sustained-motion threshold: the smaller of `0.025 m/s` or 50% of the
  requested command, so a correct very-slow gait is not punished as stalled.

The external 523.18 g rear battery/holder model, payload randomization,
straight-line penalties, acceleration/jerk penalties, foot-slip penalty, and
touchdown penalty remain active. The exported V21 JSON sidecar must declare
the same speed/cadence mapping. Deployment reads that declaration; it never
guesses a new cadence for an older model.

## Next comparison trial

Do not compare several variables at once. After deploying the controller-only
changes, first repeat a supported 3–5 second V20 run at its minimum supported
`0.04 m/s` command. Keep the physical cutoff in reach and use the same camera
view. Also record a short hardcoded-crawl reference under the same battery and
surface conditions.

For the corrected V20 trial, compare:

- output interval distribution and cumulative missed deadlines;
- distinct encoder timestamps and reported feedback transport;
- per-joint target/measurement tracking error;
- target velocity and action saturation;
- IMU roll, pitch, yaw rate, and linear acceleration; and
- voltage/current diagnostics, acknowledging that round-robin electrical data
  remain much sparser than joint feedback.

Train and evaluate V21 separately before offering commands below `0.04 m/s` on
real hardware. A candidate should pass multiple uninterrupted simulator trials
at `0.005`, `0.01`, `0.02`, `0.04`, and `0.08 m/s`, show all four legs active,
avoid stalls/falls, and improve acceleration and lateral/yaw metrics relative
to V20. Only then should it be exported, deployed, and tried on the supported
robot in short increments.

## Current verification status

The source/configuration/documentation changes have not been executed in
Isaac Sim, trained, deployed to the Raspberry Pi, or exercised on hardware as
part of this change. This report records the intended implementation and the
existing before-fix evidence; those later verification results must be added
without overwriting this baseline.

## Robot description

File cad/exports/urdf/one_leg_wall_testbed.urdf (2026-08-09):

<?xml version="1.0"?>
<!-- cadpy:sourcePath=../../drobot_cad/urdf/one_leg_wall_testbed.py -->
<!-- cadpy:sourceHash=8d64afcd35c7637d691ead915a456d2df7fdc99c720dae08dc377fbae8630d3c -->
<robot name="st3215_one_leg_wall_testbed">
  <!--Fixed wall fixture with physically exercised 2026-07-28 one-leg limits; moving-link geometry is shared with the quadruped URDF.-->
  <material name="fixture_gray">
    <color rgba="0.36 0.39 0.43 1" />
  </material>
  <material name="mount_light">
    <color rgba="0.65 0.68 0.74 1" />
  </material>
  <material name="servo_black">
    <color rgba="0.025 0.03 0.04 1" />
  </material>
  <material name="hip_orange">
    <color rgba="0.95 0.38 0.08 1" />
  </material>
  <material name="proximal_blue">
    <color rgba="0.2 0.62 0.92 1" />
  </material>
  <material name="distal_green">
    <color rgba="0.18 0.72 0.48 1" />
  </material>
  <link name="wall_link">
    <inertial>
      <origin xyz="0 -0.095084989 -0.12" rpy="0 0 0" />
      <mass value="5" />
      <inertia ixx="0.1501666667" ixy="0" ixz="0" iyy="0.2541666667" iyz="0" izz="0.1043333333" />
    </inertial>
    <visual name="fixed_vertical_wall">
      <origin xyz="0 -0.095084989 -0.12" rpy="0 0 0" />
      <geometry>
        <box size="0.5 0.02 0.6" />
      </geometry>
      <material name="fixture_gray" />
    </visual>
    <visual name="exact_printable_hip_body_mount">
      <origin xyz="0 -0.053084989 0" rpy="1.570796327 0 1.570796327" />
      <geometry>
        <mesh filename="../stl/st3215_hip_body_mount.stl" scale="0.001 0.001 0.001" />
      </geometry>
      <material name="mount_light" />
    </visual>
    <collision name="vertical_wall_collision">
      <origin xyz="0 -0.095084989 -0.12" rpy="0 0 0" />
      <geometry>
        <box size="0.5 0.02 0.6" />
      </geometry>
    </collision>
  </link>
  <link name="hip_link">
    <inertial>
      <origin xyz="0.023744808 -0.031777881 -0.001911095" rpy="0 0 0" />
      <mass value="0.169697" />
      <inertia ixx="0.0001832517" ixy="2.4855e-05" ixz="2.392e-07" iyy="7.18098e-05" iyz="-2.529e-07" izz="0.0002314034" />
    </inertial>
    <visual name="printable_hip">
      <origin xyz="0.0286117 -0.0426117 -0.00195" rpy="-1.570796327 0 0" />
      <geometry>
        <mesh filename="../stl/st3215_hip.stl" scale="0.001 0.001 0.001" />
      </geometry>
      <material name="hip_orange" />
    </visual>
    <visual name="exact_st3215_servo">
      <origin xyz="0.0255 0 0.007475" rpy="1.570796327 0 0" />
      <geometry>
        <mesh filename="../stl/st3215_servo_visual.stl" scale="0.001 0.001 0.001" />
      </geometry>
      <material name="servo_black" />
    </visual>
    <collision name="hip_printable_proxy">
      <origin xyz="0.0266617 -0.0460425 -0.00195" rpy="0 0 0" />
      <geometry>
        <box size="0.0713 0.127308 0.04805" />
      </geometry>
    </collision>
    <collision name="hip_servo_case_collision">
      <origin xyz="0.0125 0 -0.001825" rpy="1.570796327 0 0" />
      <geometry>
        <box size="0.045223408 0.0378 0.024723408" />
      </geometry>
    </collision>
  </link>
  <link name="proximal_link">
    <inertial>
      <origin xyz="0.07301168 -2.1551e-05 -0.000924466" rpy="0 0 0" />
      <mass value="0.215137" />
      <inertia ixx="7.47088e-05" ixy="5.653e-07" ixz="-6.9897e-06" iyy="0.0005598933" iyz="3.56e-08" izz="0.0005075793" />
    </inertial>
    <visual name="printable_proximal_upper_arm">
      <origin xyz="0.0948117 -0.012 0" rpy="0 0 0" />
      <geometry>
        <mesh filename="../stl/upper_arm.stl" scale="0.001 0.001 0.001" />
      </geometry>
      <material name="proximal_blue" />
    </visual>
    <visual name="exact_st3215_servo">
      <origin xyz="0.0255 0 0.007475" rpy="1.570796327 0 0" />
      <geometry>
        <mesh filename="../stl/st3215_servo_visual.stl" scale="0.001 0.001 0.001" />
      </geometry>
      <material name="servo_black" />
    </visual>
    <collision name="proximal_arm_printable_proxy">
      <origin xyz="0.096254 0 -0.00195" rpy="0 0 0" />
      <geometry>
        <box size="0.155285 0.035229 0.0713" />
      </geometry>
    </collision>
    <collision name="st3215_servo_case_collision">
      <origin xyz="0.0125 0 -0.001825" rpy="1.570796327 0 0" />
      <geometry>
        <box size="0.045223408 0.0378 0.024723408" />
      </geometry>
    </collision>
  </link>
  <link name="distal_link">
    <inertial>
      <origin xyz="0.07301168 -2.1551e-05 -0.000924466" rpy="0 0 0" />
      <mass value="0.215137" />
      <inertia ixx="7.47088e-05" ixy="5.653e-07" ixz="-6.9897e-06" iyy="0.0005598933" iyz="3.56e-08" izz="0.0005075793" />
    </inertial>
    <visual name="printable_distal_upper_arm">
      <origin xyz="0.0948117 -0.012 0" rpy="0 0 0" />
      <geometry>
        <mesh filename="../stl/upper_arm.stl" scale="0.001 0.001 0.001" />
      </geometry>
      <material name="distal_green" />
    </visual>
    <visual name="exact_st3215_servo">
      <origin xyz="0.0255 0 0.007475" rpy="1.570796327 0 0" />
      <geometry>
        <mesh filename="../stl/st3215_servo_visual.stl" scale="0.001 0.001 0.001" />
      </geometry>
      <material name="servo_black" />
    </visual>
    <collision name="distal_arm_printable_proxy">
      <origin xyz="0.096254 0 -0.00195" rpy="0 0 0" />
      <geometry>
        <box size="0.155285 0.035229 0.0713" />
      </geometry>
    </collision>
    <collision name="st3215_servo_case_collision">
      <origin xyz="0.0125 0 -0.001825" rpy="1.570796327 0 0" />
      <geometry>
        <box size="0.045223408 0.0378 0.024723408" />
      </geometry>
    </collision>
  </link>
  <joint name="hip_abduction" type="revolute">
    <parent link="wall_link" />
    <child link="hip_link" />
    <origin xyz="0 0 0" rpy="1.570796327 0 1.570796327" />
    <axis xyz="0 0 1" />
    <limit lower="-0.7853981634" upper="0.7853981634" effort="2.941995" velocity="4.712389" />
    <dynamics damping="0.08" friction="0.02" />
  </joint>
  <joint name="hip_flexion" type="revolute">
    <parent link="hip_link" />
    <child link="proximal_link" />
    <origin xyz="0.0286117 -0.095696689 -0.00195" rpy="-1.570796327 0 -1.570796327" />
    <axis xyz="0 0 -1" />
    <limit lower="-1.570796327" upper="1.570796327" effort="2.941995" velocity="4.712389" />
    <dynamics damping="0.08" friction="0.02" />
  </joint>
  <joint name="knee" type="revolute">
    <parent link="proximal_link" />
    <child link="distal_link" />
    <origin xyz="0.159896689 0 0" rpy="0 0 0" />
    <axis xyz="0 0 -1" />
    <limit lower="-2.094395102" upper="2.094395102" effort="2.941995" velocity="4.712389" />
    <dynamics damping="0.08" friction="0.02" />
  </joint>
</robot>

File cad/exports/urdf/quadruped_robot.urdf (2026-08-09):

<?xml version="1.0"?>
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
<robot name="st3215_quadruped">
  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
  <link name="base_link">
    <inertial>
      <origin xyz="0 0 0.046485537" rpy="0 0 0" />
      <mass value="2.049119" />
      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
    </inertial>
    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
  </link>
  <link name="imu_link">
    <inertial>
      <origin xyz="-3e-06 -0.000805 0.000105" rpy="0 0 0" />
      <mass value="0.0025" />
      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
    </inertial>
    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
  </link>
  <joint name="base_to_imu" type="fixed">
    <parent link="base_link" />
    <child link="imu_link" />
    <origin xyz="0 0 0.06516" rpy="0 0 0" />
  </joint>
  <link name="camera_link">
    <inertial>
      <origin xyz="0.009261819 -2.1765e-05 0.022460669" rpy="0 0 0" />
      <mass value="0.074635989" />
      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
    </inertial>
    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
  </link>
  <link name="camera_optical_frame" />
  <joint name="base_to_camera_mount" type="fixed">
    <parent link="base_link" />
    <child link="camera_link" />
    <origin xyz="0.09 0 0.1" rpy="0 0 0" />
  </joint>
  <joint name="camera_to_optical" type="fixed">
    <parent link="camera_link" />
    <child link="camera_optical_frame" />
    <origin xyz="0.0245 0 0.023" rpy="-1.570796327 0 -1.570796327" />
  </joint>
  <link name="front_left_hip_link">
    <inertial>
      <origin xyz="0.023744808 -0.031777881 -0.001911095" rpy="0 0 0" />
      <mass value="0.169697" />
      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
    </inertial>
    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
  </link>
  <link name="front_left_proximal_link">
    <inertial>
      <origin xyz="0.07301168 -2.1551e-05 -0.000924466" rpy="0 0 0" />
      <mass value="0.215137" />
      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
    </inertial>
    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
  </link>
  <link name="front_left_distal_link">
    <inertial>
      <origin xyz="0.07301168 -2.1551e-05 -0.000924466" rpy="0 0 0" />
      <mass value="0.215137" />
      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
    </inertial>
    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
  </link>
  <joint name="front_left_hip_abduction" type="revolute">
    <parent link="base_link" />
    <child link="front_left_hip_link" />
    <origin xyz="0.06 0.170084989 0.05" rpy="1.570796327 0 1.570796327" />
    <axis xyz="0 0 1" />
    <limit lower="-0.436332313" upper="0.436332313" effort="2.941995" velocity="4.712389" />
    <dynamics damping="0.08" friction="0.02" />
  </joint>
  <joint name="front_left_hip_flexion" type="revolute">
    <parent link="front_left_hip_link" />
    <child link="front_left_proximal_link" />
    <origin xyz="0.0286117 -0.095696689 -0.00195" rpy="-1.570796327 0 -1.570796327" />
    <axis xyz="0 0 -1" />
    <limit lower="-1.047197551" upper="1.047197551" effort="2.941995" velocity="4.712389" />
    <dynamics damping="0.08" friction="0.02" />
  </joint>
  <joint name="front_left_knee" type="revolute">
    <parent link="front_left_proximal_link" />
    <child link="front_left_distal_link" />
    <origin xyz="0.159896689 0 0" rpy="0 0 0" />
    <axis xyz="0 0 -1" />
    <limit lower="-1.570796327" upper="1.570796327" effort="2.941995" velocity="4.712389" />
    <dynamics damping="0.08" friction="0.02" />
  </joint>
  <link name="rear_left_hip_link">
    <inertial>
      <origin xyz="0.023744808 -0.031777881 -0.001911095" rpy="0 0 0" />
      <mass value="0.169697" />
      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
    </inertial>
    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
  </link>
  <link name="rear_left_proximal_link">
    <inertial>
      <origin xyz="0.07301168 -2.1551e-05 -0.000924466" rpy="0 0 0" />
      <mass value="0.215137" />
      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
    </inertial>
    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
  </link>
  <link name="rear_left_distal_link">
    <inertial>
      <origin xyz="0.07301168 -2.1551e-05 -0.000924466" rpy="0 0 0" />
      <mass value="0.215137" />
      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
    </inertial>
    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
  </link>
  <joint name="rear_left_hip_abduction" type="revolute">
    <parent link="base_link" />
    <child link="rear_left_hip_link" />
    <origin xyz="-0.06 0.170084989 0.05" rpy="1.570796327 0 1.570796327" />
    <axis xyz="0 0 1" />
    <limit lower="-0.436332313" upper="0.436332313" effort="2.941995" velocity="4.712389" />
    <dynamics damping="0.08" friction="0.02" />
  </joint>
  <joint name="rear_left_hip_flexion" type="revolute">
    <parent link="rear_left_hip_link" />
    <child link="rear_left_proximal_link" />
    <origin xyz="0.0286117 -0.095696689 -0.00195" rpy="-1.570796327 0 -1.570796327" />
    <axis xyz="0 0 -1" />
    <limit lower="-1.047197551" upper="1.047197551" effort="2.941995" velocity="4.712389" />
    <dynamics damping="0.08" friction="0.02" />
  </joint>
  <joint name="rear_left_knee" type="revolute">
    <parent link="rear_left_proximal_link" />
    <child link="rear_left_distal_link" />
    <origin xyz="0.159896689 0 0" rpy="0 0 0" />
    <axis xyz="0 0 -1" />
    <limit lower="-1.570796327" upper="1.570796327" effort="2.941995" velocity="4.712389" />
    <dynamics damping="0.08" friction="0.02" />
  </joint>
  <link name="front_right_hip_link">
    <inertial>
      <origin xyz="0.023744808 -0.031777881 -0.001911095" rpy="0 0 0" />
      <mass value="0.169697" />
      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
    </inertial>
    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
  </link>
  <link name="front_right_proximal_link">
    <inertial>
      <origin xyz="0.07301168 -2.1551e-05 -0.000924466" rpy="0 0 0" />
      <mass value="0.215137" />
      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
    </inertial>
    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
  </link>
  <link name="front_right_distal_link">
    <inertial>
      <origin xyz="0.07301168 -2.1551e-05 -0.000924466" rpy="0 0 0" />
      <mass value="0.215137" />
      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
    </inertial>
    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
  </link>
  <joint name="front_right_hip_abduction" type="revolute">
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

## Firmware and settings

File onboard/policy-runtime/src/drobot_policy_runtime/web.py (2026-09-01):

"""LAN dashboard for live IMU and print-only policy inspection."""

from __future__ import annotations

import argparse
import json
import math
import secrets
import socket
import threading
import time
from http.server import BaseHTTPRequestHandler, ThreadingHTTPServer
from importlib.resources import files
from pathlib import Path
from typing import Any
from urllib.parse import parse_qs, urlsplit

import numpy as np

from .contract import ACTION_NAMES, SERVO_ID_BY_ACTION_NAME
from .policy import OnnxWalkingPolicy
from .runtime import MotorSink, PolicyCommand, PolicyStepSample, WalkingPolicyLoop
from .sources import (
    Bno085ImuSource,
    ImuSample,
    ImuSource,
    LevelImuSource,
    NeutralJointStateSource,
)


class DashboardState:
    def __init__(self, imu_backend: str) -> None:
        self._lock = threading.RLock()
        self._state: dict[str, Any] = {
            "running": False,
            "status": "stopped",
            "error": None,
            "imu_backend": imu_backend,
            "forward_m_s": 0.15,
            "motor_output_enabled": False,
            "imu": None,
            "motors": [],
            "last_policy_time_s": None,
        }

    def update(self, **values: Any) -> None:
        with self._lock:
            self._state.update(values)

    def snapshot(self) -> dict[str, Any]:
        with self._lock:
            return json.loads(json.dumps(self._state))


class RecordingImuSource:
    def __init__(self, source: ImuSource, state: DashboardState) -> None:
        self._source = source
        self._state = state

    def read(self) -> ImuSample:
        sample = self._source.read()
        self._state.update(
            imu={
                "angular_velocity_rad_s": [
                    round(float(value), 5)
                    for value in sample.angular_velocity_body_rad_s
                ],
                "projected_gravity": [
                    round(float(value), 5) for value in sample.projected_gravity_body
                ],
                "linear_acceleration_m_s2": [
                    round(float(value), 5)
                    for value in sample.linear_acceleration_body_m_s2
                ],
                "heading_yaw_rad": round(float(sample.heading_yaw_rad), 6),
                "sample_time_s": round(sample.monotonic_time_s, 6),
            }
        )
        return sample


class DashboardMotorSink(MotorSink):
    def __init__(self, state: DashboardState) -> None:
        self._state = state

    def write(
        self,
        action: np.ndarray,
        joint_target_rad: np.ndarray,
        monotonic_time_s: float,
    ) -> None:
        motors = [
            {
                "servo_id": SERVO_ID_BY_ACTION_NAME[name],
                "joint": name,
                "target_deg": round(math.degrees(float(joint_target_rad[index])), 3),
                "normalized_action": round(float(action[index]), 5),
            }
            for index, name in enumerate(ACTION_NAMES)
        ]
        self._state.update(
            motors=motors,
            last_policy_time_s=round(monotonic_time_s, 6),
        )


class PolicySupervisor:
    def __init__(
        self,
        model_path: Path,
        imu_source: ImuSource,
        imu_backend: str,
        control_hz: float,
    ) -> None:
        self.state = DashboardState(imu_backend)
        self._policy = OnnxWalkingPolicy(model_path)
        self._imu_source = RecordingImuSource(imu_source, self.state)
        self._control_hz = control_hz
        self._stop_event = threading.Event()
        self._thread: threading.Thread | None = None
        self._loop: WalkingPolicyLoop | None = None
        self._lock = threading.RLock()
        heading = self._policy.heading_hold_config
        self.state.update(
            heading_hold={
                "enabled": heading.enabled,
                "mode": heading.mode,
                "kp_s": heading.kp_s,
                "max_correction_rad_s": heading.max_correction_rad_s,
                "reference_yaw_rad": None,
                "current_relative_rad": None,
                "desired_relative_rad": None,
                "error_rad": None,
                "correction_rad_s": 0.0,
                "effective_yaw_rad_s": 0.0,
            }
        )

    def start(self, forward_m_s: float) -> None:
        if not 0.0 <= forward_m_s <= 0.20:
            raise ValueError("forward_m_s must be in [0.0, 0.20]")
        with self._lock:
            if self._thread is not None and self._thread.is_alive():
                self.set_command(forward_m_s)
                return
            self._stop_event = threading.Event()
            self._loop = WalkingPolicyLoop(
                self._policy,
                self._imu_source,
                NeutralJointStateSource(),
                DashboardMotorSink(self.state),
                command=PolicyCommand(forward_m_s=forward_m_s),
                control_hz=self._control_hz,
                step_observer=self._update_policy_step,
            )
            self.state.update(
                running=True,
                status="running",
                error=None,
                forward_m_s=forward_m_s,
            )
            self._thread = threading.Thread(
                target=self._run,
                name="drobot-policy-loop",
                daemon=True,
            )
            self._thread.start()

    def _update_policy_step(self, sample: PolicyStepSample) -> None:
        self.state.update(
            heading_hold={
                "enabled": sample.heading_hold_enabled,
                "mode": self._policy.heading_hold_config.mode,
                "kp_s": self._policy.heading_hold_config.kp_s,
                "max_correction_rad_s": (
                    self._policy.heading_hold_config.max_correction_rad_s
                ),
                "reference_yaw_rad": sample.heading_reference_yaw_rad,
                "current_relative_rad": sample.heading_current_relative_rad,
                "desired_relative_rad": sample.heading_desired_relative_rad,
                "error_rad": sample.heading_error_rad,
                "correction_rad_s": sample.heading_correction_rad_s,
                "effective_yaw_rad_s": sample.effective_yaw_rad_s,
            }
        )

    def _run(self) -> None:
        try:
            assert self._loop is not None
            self._loop.run(stop_event=self._stop_event)
            self.state.update(running=False, status="stopped")
        except Exception as exc:
            self.state.update(running=False, status="error", error=str(exc))

    def set_command(self, forward_m_s: float) -> None:
        if not 0.0 <= forward_m_s <= 0.20:
            raise ValueError("forward_m_s must be in [0.0, 0.20]")
        with self._lock:
            if self._loop is not None:
                self._loop.command = PolicyCommand(forward_m_s=forward_m_s)
            self.state.update(forward_m_s=forward_m_s)

    def stop(self) -> None:
        self._stop_event.set()
        thread = self._thread
        if thread is not None:
            thread.join(timeout=2.0)
        self.state.update(running=False, status="stopped")


class PolicyDashboardServer(ThreadingHTTPServer):
    daemon_threads = True
    allow_reuse_address = True

    def __init__(
        self,
        address: tuple[str, int],
        supervisor: PolicySupervisor,
        token: str,
    ) -> None:
        super().__init__(address, PolicyDashboardHandler)
        self.supervisor = supervisor
        self.token = token


class PolicyDashboardHandler(BaseHTTPRequestHandler):
    server: PolicyDashboardServer

    def log_message(self, format: str, *args: Any) -> None:
        return

    def _authorized(self) -> bool:
        if not self.server.token:
            return True
        query_token = parse_qs(urlsplit(self.path).query).get("token", [""])[0]
        header_token = self.headers.get("X-Drobot-Token", "")
        return secrets.compare_digest(self.server.token, header_token or query_token)

    def _send_json(self, status: int, payload: dict[str, Any]) -> None:
        data = json.dumps(payload, separators=(",", ":")).encode("utf-8")
        self.send_response(status)
        self.send_header("Content-Type", "application/json")
        self.send_header("Content-Length", str(len(data)))
        self.send_header("Cache-Control", "no-store")
        self.end_headers()
        self.wfile.write(data)

    def _read_json(self) -> dict[str, Any]:
        length = int(self.headers.get("Content-Length", "0"))
        if length > 4096:
            raise ValueError("request body is too large")
        if length == 0:
            return {}
        value = json.loads(self.rfile.read(length))
        if not isinstance(value, dict):
            raise ValueError("request body must be a JSON object")
        return value

    def do_GET(self) -> None:
        path = urlsplit(self.path).path
        if path == "/api/state":
            if not self._authorized():
                self._send_json(403, {"error": "invalid control token"})
                return
            self._send_json(200, self.server.supervisor.state.snapshot())
            return

        static_names = {"/": "index.html", "/app.js": "app.js", "/app.css": "app.css"}
        name = static_names.get(path)
        if name is None:
            self.send_error(404)
            return
        resource = files("drobot_policy_runtime").joinpath("web_static", name)
        data = resource.read_bytes()
        content_type = {
            "index.html": "text/html; charset=utf-8",
            "app.js": "text/javascript; charset=utf-8",
            "app.css": "text/css; charset=utf-8",
        }[name]
        self.send_response(200)
        self.send_header("Content-Type", content_type)
        self.send_header("Content-Length", str(len(data)))
        self.send_header("Cache-Control", "no-store")
        self.end_headers()
        self.wfile.write(data)

    def do_POST(self) -> None:
        if not self._authorized():
            self._send_json(403, {"error": "invalid control token"})
            return
        path = urlsplit(self.path).path
        try:
            body = self._read_json()
            if path == "/api/start":
                self.server.supervisor.start(float(body.get("forward_m_s", 0.15)))
            elif path == "/api/command":
                self.server.supervisor.set_command(float(body["forward_m_s"]))
            elif path == "/api/stop":
                self.server.supervisor.stop()
            else:
                self._send_json(404, {"error": "unknown endpoint"})
                return
            self._send_json(200, self.server.supervisor.state.snapshot())
        except (KeyError, TypeError, ValueError, json.JSONDecodeError) as exc:
            self._send_json(400, {"error": str(exc)})


def _i2c_address(text: str) -> int:
    value = int(text, 0)
    if not 0 <= value <= 0x7F:
        raise argparse.ArgumentTypeError("I2C address must be between 0x00 and 0x7f")
    return value


def main() -> None:
    parser = argparse.ArgumentParser(description="Drobot print-only policy dashboard")
    parser.add_argument("--model", required=True)
    parser.add_argument("--imu", choices=("bno085", "level"), default="bno085")
    parser.add_argument("--imu-address", type=_i2c_address, default=0x4A)
    parser.add_argument("--imu-axis-map", default="+x,+y,+z")
    parser.add_argument("--bind", default="0.0.0.0")
    parser.add_argument("--port", type=int, default=8090)
    parser.add_argument("--control-token", default="")
    parser.add_argument("--control-hz", type=float, default=60.0)
    args = parser.parse_args()

    if not 1 <= args.port <= 65535:
        parser.error("--port must be in [1, 65535]")
    token = args.control_token.strip()
    if token and len(token) < 16:
        parser.error("--control-token must contain at least 16 characters")
    imu_source: ImuSource = (
        Bno085ImuSource(args.imu_address, args.imu_axis_map)
        if args.imu == "bno085"
        else LevelImuSource()
    )
    supervisor = PolicySupervisor(
        Path(args.model), imu_source, args.imu, args.control_hz
    )
    server = PolicyDashboardServer((args.bind, args.port), supervisor, token)
    host = socket.gethostname()
    print("PRINT-ONLY POLICY DASHBOARD: this process cannot command the servo bus.")
    url = f"http://{host}.local:{server.server_port}/"
    if token:
        url += f"?token={token}"
    print(f"Open: {url}", flush=True)
    try:
        server.serve_forever(poll_interval=0.2)
    except KeyboardInterrupt:
        pass
    finally:
        supervisor.stop()
        server.server_close()


if __name__ == "__main__":
    main()

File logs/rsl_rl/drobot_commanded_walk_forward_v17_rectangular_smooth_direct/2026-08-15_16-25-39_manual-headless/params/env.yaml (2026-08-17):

viewer:
  eye: !!python/tuple
  - -1.4
  - -1.25
  - 0.65
  lookat: !!python/tuple
  - 0.0
  - 0.0
  - -0.15
  cam_prim_path: /OmniverseKit_Persp
  resolution: !!python/tuple
  - 1280
  - 720
  origin_type: asset_root
  env_index: 0
  asset_name: robot
  body_name: null
sim:
  device: cuda:0
  dt: 0.008333333333333333
  gravity: !!python/tuple
  - 0.0
  - 0.0
  - -9.81
  physics_prim_path: /physicsScene
  physics_material:
    func: isaaclab.sim.spawners.materials.physics_materials:spawn_rigid_body_material
    static_friction: 1.1
    dynamic_friction: 0.9
    restitution: 0.0
    density: null
    compliant_contact_stiffness: null
    compliant_contact_damping: null
    compliant_contact_acceleration_spring: null
    friction_combine_mode: multiply
    restitution_combine_mode: multiply
    damping_combine_mode: null
    _usd_applied_schema: PhysxMaterialAPI
    _usd_field_exceptions: {}
    _usd_namespace: physxMaterial
  use_fabric: true
  render_interval: 2
  enable_scene_query_support: false
  use_newton_actuators: false
  physics:
    class_type: isaaclab_physx.physics.physx_manager:PhysxManager
    solver_type: 1
    solve_articulation_contact_last: false
    min_position_iteration_count: 1
    max_position_iteration_count: 255
    min_velocity_iteration_count: 0
    max_velocity_iteration_count: 255
    enable_scene_query_support: false
    enable_ccd: false
    enable_stabilization: false
    enable_external_forces_every_iteration: true
    enable_enhanced_determinism: false
    bounce_threshold_velocity: 0.5
    friction_offset_threshold: 0.04
    friction_correlation_distance: 0.025
    gpu_max_rigid_contact_count: 8388608
    gpu_max_rigid_patch_count: 524288
    gpu_found_lost_pairs_capacity: 2097152
    gpu_found_lost_aggregate_pairs_capacity: 33554432
    gpu_total_aggregate_pairs_capacity: 2097152
    gpu_collision_stack_size: 67108864
    gpu_heap_capacity: 67108864
    gpu_temp_buffer_capacity: 16777216
    gpu_max_num_partitions: 8
    gpu_max_soft_body_contacts: 1048576
    gpu_max_particle_contacts: 1048576
  create_stage_in_memory: false
  logging_level: WARNING
  save_logs_to_file: true
  log_dir: null
  visualizer_cfgs: []
ui_window_class_type: isaaclab.envs.ui.base_env_window:BaseEnvWindow
seed: 4817
decimation: 2
is_finite_horizon: false
compute_final_obs: false
episode_length_s: 32.0
scene:
  class_type: isaaclab.scene.interactive_scene:InteractiveScene
  num_envs: 128
  env_spacing: 8.0
  lazy_sensor_update: true
  replicate_physics: true
  filter_collisions: true
  clone_in_fabric: true
  clone_cfg:
    clone_strategy: isaaclab.cloner.cloner_strategies:sequential
    clone_combinations: []
    device: cpu
    clone_regex: /World/envs/env_.*
    replicate_physics: true
events: null
observation_space: 48
num_observations: null
state_space: 56
num_states: null
observation_noise_model: null
action_space: 12
num_actions: null
action_noise_model: null
rerender_on_reset: false
num_rerenders_on_reset: 0
wait_for_textures: true
xr: null
log_dir: C:\Users\roman\Documents\dev\drobot2\logs\rsl_rl\drobot_commanded_walk_forward_v17_rectangular_smooth_direct\2026-08-15_16-25-39_manual-headless
video_recorder:
  class_type: isaaclab.envs.utils.video_recorder:VideoRecorder
  env_render_mode: null
  eye: !!python/tuple
  - -1.4
  - -1.25
  - 0.65
  lookat: !!python/tuple
  - 0.0
  - 0.0
  - -0.15
  backend_source: visualizer
  window_width: 1280
  window_height: 720
disable_time_limit: false
initial_training_horizon_s: 8.0
final_training_horizon_s: 32.0
episode_horizon_curriculum_steps: 64000
terrain:
  class_type: isaaclab.terrains.terrain_importer:TerrainImporter
  collision_group: -1
  prim_path: /World/ground
  num_envs: 128
  terrain_type: plane
  terrain_generator: null
  usd_path: null
  env_spacing: 8.0
  use_terrain_origins: true
  visual_material:
    func: isaaclab.sim.spawners.materials.visual_materials:spawn_preview_surface
    diffuse_color: !!python/tuple
    - 0.2
    - 0.23
    - 0.2
    emissive_color: !!python/tuple
    - 0.0
    - 0.0
    - 0.0
    roughness: 0.5
    metallic: 0.0
    opacity: 1.0
  physics_material:
    func: isaaclab.sim.spawners.materials.physics_materials:spawn_rigid_body_material
    static_friction: 1.1
    dynamic_friction: 0.9
    restitution: 0.0
    density: null
    compliant_contact_stiffness: null
    compliant_contact_damping: null
    compliant_contact_acceleration_spring: null
    friction_combine_mode: multiply
    restitution_combine_mode: multiply
    damping_combine_mode: null
    _usd_applied_schema: PhysxMaterialAPI
    _usd_field_exceptions: {}
    _usd_namespace: physxMaterial
  max_init_terrain_level: null
  debug_vis: false
robot:
  class_type: isaaclab.assets.articulation.articulation:Articulation
  cloning_contexts: null
  prim_path: /World/envs/env_.*/Robot
  spawn:
    func: isaaclab.sim.spawners.from_files.from_files:spawn_from_usd
    visible: true
    semantic_tags: null
    copy_from_source: true
    spawn_path: null
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

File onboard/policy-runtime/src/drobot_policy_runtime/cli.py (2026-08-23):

"""Print-only Raspberry Pi policy entry point."""

from __future__ import annotations

import argparse

from .policy import OnnxWalkingPolicy
from .runtime import PolicyCommand, PrintMotorSink, WalkingPolicyLoop
from .sources import Bno085ImuSource, LevelImuSource, NeutralJointStateSource


def _address(text: str) -> int:
    value = int(text, 0)
    if not 0 <= value <= 0x7F:
        raise argparse.ArgumentTypeError("I2C address must be between 0x00 and 0x7f")
    return value


def main() -> None:
    parser = argparse.ArgumentParser(
        description="Run the configured walking policy and print motor targets only."
    )
    parser.add_argument("--model", required=True)
    parser.add_argument("--imu", choices=("bno085", "level"), default="bno085")
    parser.add_argument("--imu-address", type=_address, default=0x4A)
    parser.add_argument("--imu-axis-map", default="+x,+y,+z")
    parser.add_argument("--forward-m-s", type=float, default=0.15)
    parser.add_argument("--duration-s", type=float, default=0.0)
    parser.add_argument("--control-hz", type=float, default=60.0)
    parser.add_argument("--print-hz", type=float, default=5.0)
    args = parser.parse_args()

    if not 0.0 < args.print_hz <= args.control_hz:
        parser.error("--print-hz must be positive and no greater than --control-hz")
    imu = (
        Bno085ImuSource(args.imu_address, args.imu_axis_map)
        if args.imu == "bno085"
        else LevelImuSource()
    )
    print(
        "PRINT-ONLY MODE: the policy uses neutral placeholder joint feedback and "
        "will not open or command the servo bus.",
        flush=True,
    )
    loop = WalkingPolicyLoop(
        OnnxWalkingPolicy(args.model),
        imu,
        NeutralJointStateSource(),
        PrintMotorSink(args.print_hz),
        command=PolicyCommand(forward_m_s=args.forward_m_s),
        control_hz=args.control_hz,
    )
    try:
        loop.run(args.duration_s)
    except KeyboardInterrupt:
        pass


if __name__ == "__main__":
    main()

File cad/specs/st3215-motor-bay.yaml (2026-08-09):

schema_version: 1
part_id: st3215_motor_bay
source: drobot_cad/parts/st3215_motor_bay.py
vendor_reference: vendor/servos/waveshare_feetech_st3215_servo.step
units: mm

catalog_envelope:
  height_y_mm: 37.8
  width_z_mm: 24.7234
  max_x_mm: 9.6117

socket:
  clearance_y_per_side_mm: 0.25
  clearance_z_total_mm: 0.25
  wall_mm: 3.0
  length_x_mm: 16.0
  stop_thickness_mm: 1.5
  boolean_overtravel_mm: 0.6
  cable_window_y_mm: 16.0
  cable_window_z_mm: 14.0
  outer_side_perimeter_fillet_radius_mm: 2.0

ventilation:
  side_walls: both
  pattern: diamond
  columns_x_mm: [-11.25, -4.75]
  rows_z_mm: [-12.0, -4.0, 4.0, 12.0]
  diamond_width_x_mm: 3.6
  diamond_height_z_mm: 5.2
  wall_overtravel_mm: 0.6

mount_holes:
  y_spacing_mm: 20.5
  top_x_mm: -6.8117
  bottom_x_mm: -3.0617
  through_diameter_mm: 2.0
  counterbore_diameter_mm: 4.0
  inner_pilot_depth_mm: 2.95

frames:
  frame_attachment_datum:
    xyz_mm: [0.0, 0.0, 0.0]
    axis: [1.0, 0.0, 0.0]
  frame_servo_install:
    xyz_mm: [-11.1117, 0.0, 9.425]
    rotation_xyz_deg: [90.0, 0.0, 0.0]
    axis: [1.0, 0.0, 0.0]

generated_baseline:
  solid_count: 1
  bounds:
    min_xyz_mm: [-16.0, -15.6117, -22.025]
    max_xyz_mm: [0.0, 15.6117, 22.025]
    size_xyz_mm: [16.0, 31.2234, 44.05]
  volume_mm3: 9082.938146167759
  kernel_tolerance_mm: 0.01
  volume_relative_tolerance: 1.0e-5

status:
  fit_allowances: preliminary FDM test fit
  vendor_variant: exact ST3215 catalog model

acceptance_tests:
  - geometry is valid
  - model contains one connected solid
  - exact catalog servo produces the captured keyed cavity
  - generated bounds match the migrated source
  - cable window and four mount access locations remain open
  - eight diamond vents remain open on each broad side wall
  - the eight marked broad-side perimeter edges have 2 mm cosmetic fillets

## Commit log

2026-07-25 Initialize Drobot2 monorepo
    [st3215-motor-bay.yaml, st3215_motor_bay-ventilation-three-view-markup.json]
2026-07-25 Update motor bay ventilation baseline
    [st3215-motor-bay.yaml]
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2026-07-25 feat: add reusable ST3215 servo output fork component
    - Introduced a new JSON markup file for the ST3215 servo output fork's front view.
    - Created a Python module for the ST3215 servo output fork, defining its geometry and behavior.
    - Added a YAML specification for the ST3215 servo output fork, detailing its parameters and acceptance tests.
    - Implemented unit tests to validate the functionality and integration of the ST3215 servo output fork within the robot arm assembly.
    [st3215-motor-bay.yaml, st3215-servo-output-fork.yaml, st3215_motor_bay-outer-shell-fillet-three-view-markup.json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]
2026-07-25 Reinforce ST3215 servo output fork root
    [st3215-servo-output-fork-perpendicular-root-three-view-markup.json, st3215-servo-output-fork.yaml]
2026-07-25 feat: add ST3215 hip assembly and orientation preview
    - Implemented the hip orientation preview assembly in `hip_orientation_preview.py`.
    - Created the ST3215 hip part in `st3215_hip.py`, preserving user-approved orientations.
    - Added YAML specifications for both the hip orientation preview and the ST3215 hip.
    - Developed unit tests for the hip orientation preview and ST3215 hip to ensure proper alignment and collision checks.
2026-07-25 Add three-view markup for st3215 servo output fork with extended edge design
    [st3215-servo-output-fork-half-oval-extension-three-view-markup.json, st3215-servo-output-fork.yaml]
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2026-07-26 Add quadruped body and leg CAD assemblies
    [robot-leg.yaml]
2026-07-26 Track generated CAD deliverables
    [hip_orientation_preview.step, quadruped_body_base.3mf, quadruped_body_base.step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]
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2026-07-26 Add corrected CAD-based Isaac articulation review
2026-07-26 Build CAD-based URDF and Isaac articulation assets
    [quadruped_robot.urdf, st3215_hip_body_mount.step, st3215_motor_bay.step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]
2026-07-26 Add body wiring and utility mounting holes
    [quadruped_body_base.3mf, quadruped_body_base.step, quadruped_body_base.stl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]
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2026-07-26 Enable guarded quadruped self-collision
    [quadruped_robot.urdf]
2026-07-26 Add LeKiwi-compatible camera mount
    [lekiwi_camera_body_fit_preview.step, quadruped_body_lid.3mf, quadruped_body_lid.step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]
2026-07-26 Connect mounted camera to Isaac Sim
    [quadruped_robot.urdf]
2026-07-26 Add body IMU mount and Isaac sensor
    [adafruit_bno085_stemma_qt.step, adafruit_bno085_stemma_qt.stl, quadruped_electronics_tray.3mf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]
2026-07-27 Add quadruped body lid and electronics tray components
    - Implemented `quadruped_body_lid.py` to create a removable lid with locator lip and various openings for ventilation and cable ports.
    - Implemented `quadruped_electronics_tray.py` to create a ventilated tray for electronics above the battery bay.
    - Added specifications for the quadruped body and robot leg in YAML format, detailing dimensions, components, and assembly requirements.
    - Created unit tests for the quadruped body, lid, and electronics tray to ensure valid solid generation and proper dimensions.
    - Developed assembly tests for the quadruped robot and robot leg to verify component relationships and positional accuracy.
    [Bus Servo Adapter (A).step, lekiwi_12v_5ah_battery_reference.stl]
2026-07-27 Add Fusion-ready quadruped assembly handoff
    [lekiwi_12v_battery_reference.step, quadruped_body_hardware_fit_preview.step, quadruped_electronics_tray.step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]
2026-07-27 Add quadruped IMU cover and corresponding tests
    - Implemented a removable bolt-on protection cover for the BNO085 sensor, including design parameters and mounting specifications.
    - Created functions to generate the cover shape, roof, spacer sleeves, and mounting holes.
    - Added a script to export the cover as a STEP file.
    - Developed unit tests to validate the cover's dimensions, hole placements, and fit with the electronics tray and body lid.
    [quadruped_body_hardware_fit_preview.step, quadruped_imu_cover.3mf, quadruped_imu_cover.step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]
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2026-07-29 Document quadruped electrical system
    [power-budget.csv]
2026-07-30 Add one-leg Isaac wall test
    [one_leg_wall_testbed.urdf]
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2026-08-01 Audit torque-aware live stair transfer
    [monitor.csv]
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2026-08-02 Add V45 stair transfer diagnostic policy
    [monitor.csv]
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2026-08-02 Train first-tread loaded-contact policy
    [monitor.csv]
2026-08-02 Land first strict stair foothold
    [monitor.csv]
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2026-08-03 Train pure PPO hip and reset stair variants
    [env.yaml]
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2026-08-03 Train gradual lower-reset stair PPO
    [env.yaml]
2026-08-03 Bridge PPO into deeper stair resets
    [env.yaml]
2026-08-03 Train harder-reset pure PPO stair policy
    [env.yaml]
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2026-08-09 Consolidate latest robot hardware, CAD, and training artifacts
    [lekiwi_camera_body_fit_preview.step, monitor.csv, quadruped_body_base.3mf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]
2026-08-09 refactor repository layout and hardware runtime
    [Bus Servo Adapter (A).step, adafruit_bno085_stemma_qt.step, adafruit_bno085_stemma_qt.stl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]
2026-08-09 Refactor code structure for improved readability and maintainability
    [tpu_fork_shoe.3mf, tpu_fork_shoe.step, tpu_fork_shoe.stl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]
2026-08-09 feat: implement hardware gait sequence V1 with updated joint targets and telemetry
    - Updated crawl-walk specifications to reflect new servo torque and speed settings.
    - Introduced a new hardware joint sequence function to manage gait transitions.
    - Refactored four-leg control to utilize the new gait sequence, replacing coordinated motion.
    - Enhanced front-end to include a settings dialog for error management and command execution.
    - Removed deprecated safety checks from the UI and CSS.
    - Added permanent error logging functionality to track and display persistent issues.
    - Created a detailed documentation file for the hardware gait sequence, outlining the joint transitions and telemetry thres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
2026-08-17 Add fork shoe and coordinated walking workflows
    [rectangular_fork_shoe.3mf, rectangular_fork_shoe.step, rectangular_fork_shoe.stl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]
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2026-08-22 Add battery and Raspberry Pi enclosures
    [cm5202_battery_box.3mf, cm5202_battery_box.step, cm5202_battery_box.stl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]
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2026-08-22 Collapse repeated servo disconnect errors
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2026-08-23 Add controller enclosure and carry handle CAD
    [quadruped_carry_training_handle.3mf, quadruped_carry_training_handle.step, quadruped_carry_training_handle.stl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]
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2026-08-24 Reverse motor 5 direction
2026-08-24 Reverse motor 6 direction
2026-08-25 Add two-color AprilTag body marker
    [apriltag_body_marker.3mf, apriltag_body_marker.step, apriltag_body_marker_black.stl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]
2026-08-25 Repair Bambu multi-color AprilTag 3MF
    [apriltag_body_marker.3mf, apriltag_body_marker_bambu_source.3mf]
2026-08-26 Improve real-robot RL control and debug workflow
    Synchronize servo I/O with actual elapsed time, avoid catch-up command bursts, and decouple feedback reads from policy inference. Add low-speed cadence training support, AprilTag mounting CAD, and a privacy-sanitized real-walk baseline with analysis.
    [apriltag_body_marker.3mf, apriltag_body_marker.step, apriltag_body_marker_white.stl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]
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2026-09-21 Save ankle calibration, diagonal IK control, and overnight walking model
    Include dashboard ankle coordination and motor timing changes, V24-V26 walking training sources, checkpoint 2549 and its Gaussian actor export, the approved checkpoint 549 fallback, evaluation evidence, and recordings. Document the remaining drift issue and the matching-controller requirement before Pi deployment. No tests, builds, simulations, UI checks, or hardware checks were run for this publication.
